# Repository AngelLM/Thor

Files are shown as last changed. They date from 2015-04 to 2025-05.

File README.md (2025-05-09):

<h1 align="center">
 <a href="http://thor.angel-lm.com">
    <picture>
      <source height="80" media="(prefers-color-scheme: dark)" srcset="doc/logo_dark.svg">
      Fiber
    </picture>
  </a>

 <br>

 <a href="http://thor.angel-lm.com/">
     
 </a>
 <a href="http://thor.angel-lm.com/worldwide/">
     
 </a>
 <a href="http://thor.angel-lm.com/forums/">
     
 </a>
 <a href="https://discord.com/invite/a5dSVqSUK5">
     
 </a>
 <a href="https://creativecommons.org/licenses/by-sa/4.0/legalcode">
     
 </a>
</h1>
<p align="center">
 <em><b>Thor</b> is an open source, 3D printed, 6 degrees of freedom robotic arm. Designed to be affordable and accessible, Thor is ideal for educational settings, makers, and robotics enthusiasts. With a height of 625mm it has the capacity to lift up to 750g. Its yaw-roll-roll-yaw-roll-yaw configuration is common in industrial manipulators.</em>
</p>
<p align="center">
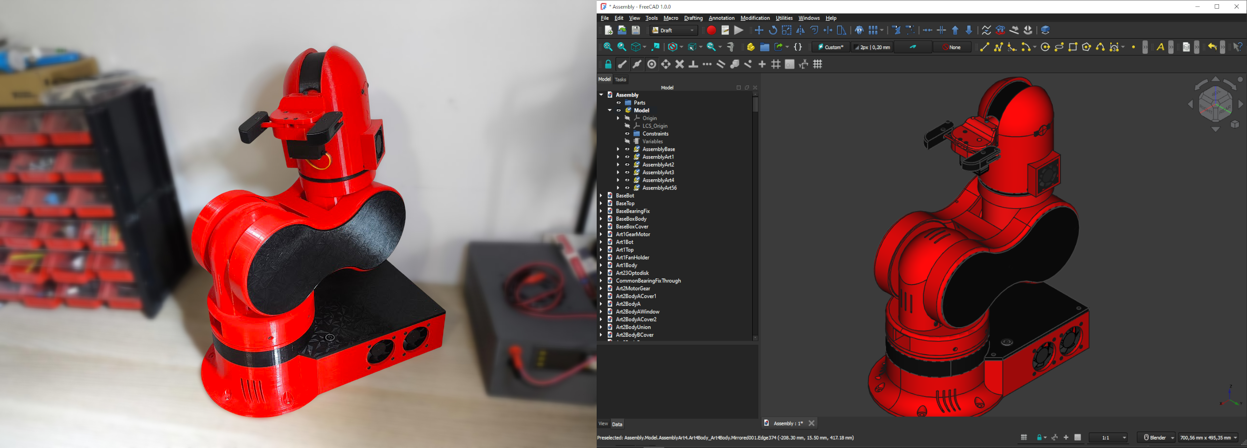
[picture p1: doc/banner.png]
 
</p>

## ✨ Key Features

- 🧩 **Born Open Source**: Designed using open source software such as FreeCAD, KiCAD, GRBL, RRF and ROS.
- 🕊️ **Released Open Source**: All source files published under CC-BY-SA-4.0 license.
- 💰 **Low Cost**: Hardware cost below 350€.
- 📚  **Suitable for education**: Perfect for robotics courses in schools and universities, there are already success cases!
- 🧰 **G-code Controlled**: Uses the same language as 3d printers and CNCs to move.
- 🐳 **ROS2 Integration**: Available implementation using Docker for flexibility.

## 📦 Repository Structure
- `freecad-src` – Source files of 3D models created with FreeCAD
- `mods` – Modified models and improvements to standard models
- `stl` – Printable STL files
- `step` – STEP files

## 🔗 Related Repositories
- [**Thor-ROS**](https://github.com/AngelLM/Thor-ROS): ROS2 & Moveit2 configuration files and packages to work with Thor.
- [**ThorControlPCB**](https://github.com/AngelLM/ThorControlPCB): Source & manufacture files of Arduino Mega shield designed to control Thor.
- [**Asgard**](https://github.com/AngelLM/Asgard): Control software for thor motors with a simple interface.

## 🚀 Getting Started

1. **Read the Documentation**: Comprehensive guides on printing, assembly, electronics, and firmware are available at [thor.angel-lm.com/documentation](http://thor.angel-lm.com/documentation/).
2. **Print the Parts**: Use the STL files in this repository.
3. **Get the Hardware**: Take a look to the [Bill of Materials](http://thor.angel-lm.com/documentation/bom/).
4. **Assemble the Robot**: See [here](http://thor.angel-lm.com/documentation/assembly/) for assembly videos and interactive instructions. 
5. **Assemble & Setup the Electronics**: The [Wiring & Setup](http://thor.angel-lm.com/documentation/electronics/) guide will help you prepare your electronic board and make the hardware connections. 
6. **Install the Firmware**: Depending on which electronics you have chosen, you will have to perform a different firmware configuration. [This page](http://thor.angel-lm.com/documentation/firmware/) explains the steps to follow.
7. **Control the Robot**: Use Asgard to move the robot. [Here](http://thor.angel-lm.com/documentation/control-software/) is how to do it.

## 🧠 Technical Specifications

- **Degrees of Freedom**: 6 (yaw-roll-roll-yaw-roll-yaw).
- **Height Stretched**: 625mm (without end effector).
- **Payload Capacity**: 750g max (including end effector weight).
- **Motors**: Stepper motors.
- **Electronics**: DIY PCB or commercial boards.
- **Transmission**: 3D printed gears, GT2 pulleys and belts.
- **Software**: FreeCAD, KiCAD, GRBL, RRF, ROS2.

## 📚 Additional Resources

- 🌐 **Official Website**: [thor.angel-lm.com](http://thor.angel-lm.com/)
- ❓ **Frequently Asked Questions**: [FAQ](http://thor.angel-lm.com/faq/)
- 💬 **Thor Community Forums**: [Thor Forums](http://thor.angel-lm.com/forums/)
- 💬 **Thor Discord Server**: [Thor Robot Community](https://discord.com/invite/a5dSVqSUK5)

## 🤝 Contributing

Contributions are welcome! If you'd like to improve Thor — whether it's design, documentation, or code — feel free to open an [Issue](https://github.com/AngelLM/Thor/issues) or submit a Pull Request.

## 📜 License

Thor is licensed under the [Creative Commons Attribution-ShareAlike 4.0 International License](https://creativecommons.org/licenses/by-sa/4.0/legalcode). You’re free to use, modify, and distribute this project under its terms.

## 🎥 Videos

Watch on YouTube (https://www.youtube.com/watch?v=F2CDeHrFr2k)

Watch on YouTube (https://www.youtube.com/watch?v=e0BGN1eIjiI)

Watch on YouTube (https://www.youtube.com/watch?v=nDCN46trJvs)

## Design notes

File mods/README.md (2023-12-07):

# Modifications

In this folder you'll find the FreeCAD, STEP and STL files for modifications that some users did. 

<br/>

## Easier printing

### These modifications make Thor easier to print (split parts or smaller modifications). 

<br/>

* [Danny-VdH](https://github.com/Danny-VdH) 
    * Art2BodyASmall, Art2BodyBSmall, Art2BodyBCoverSmall & Art4Body modifications

<br/>

* [Ctrl-Alt-Dude](http://www.thingiverse.com/ctrl-alt-dude/about)
    * BaseBot190mm modification (Deprecated)

<br/>

## End Effectors

### User-designed tools and end effectors for Thor

<br/>

* [ImerNChavez](https://github.com/imernchavez)
    * SuctionCupToolHolder

<br/>

## Tolerances and different hardware

### Modifications to parts that improve print tolerance or serve to use components other than those listed in the BOM.

<br/>

* [se1exin](https://github.com/se1exin) 
    * Art4BearingRing_5.98mm_Balls

<br/>

Thank you guys ;)

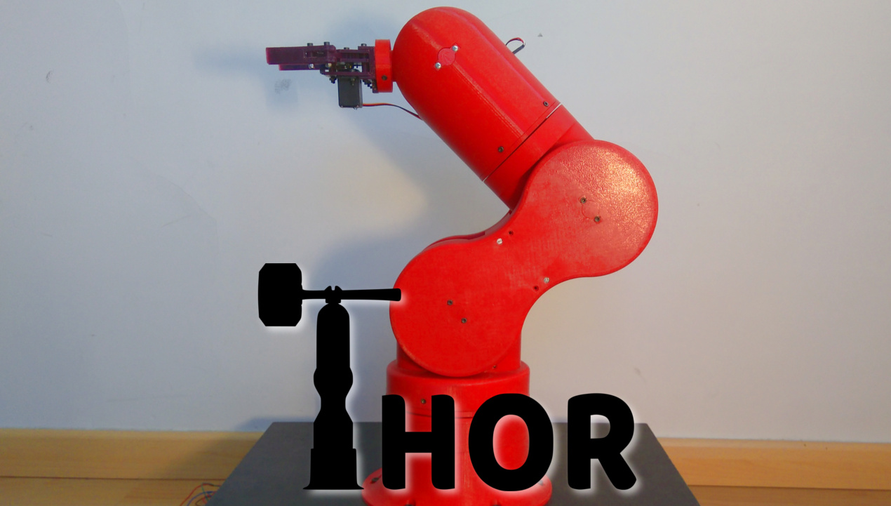
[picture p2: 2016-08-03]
doc/main.jpg

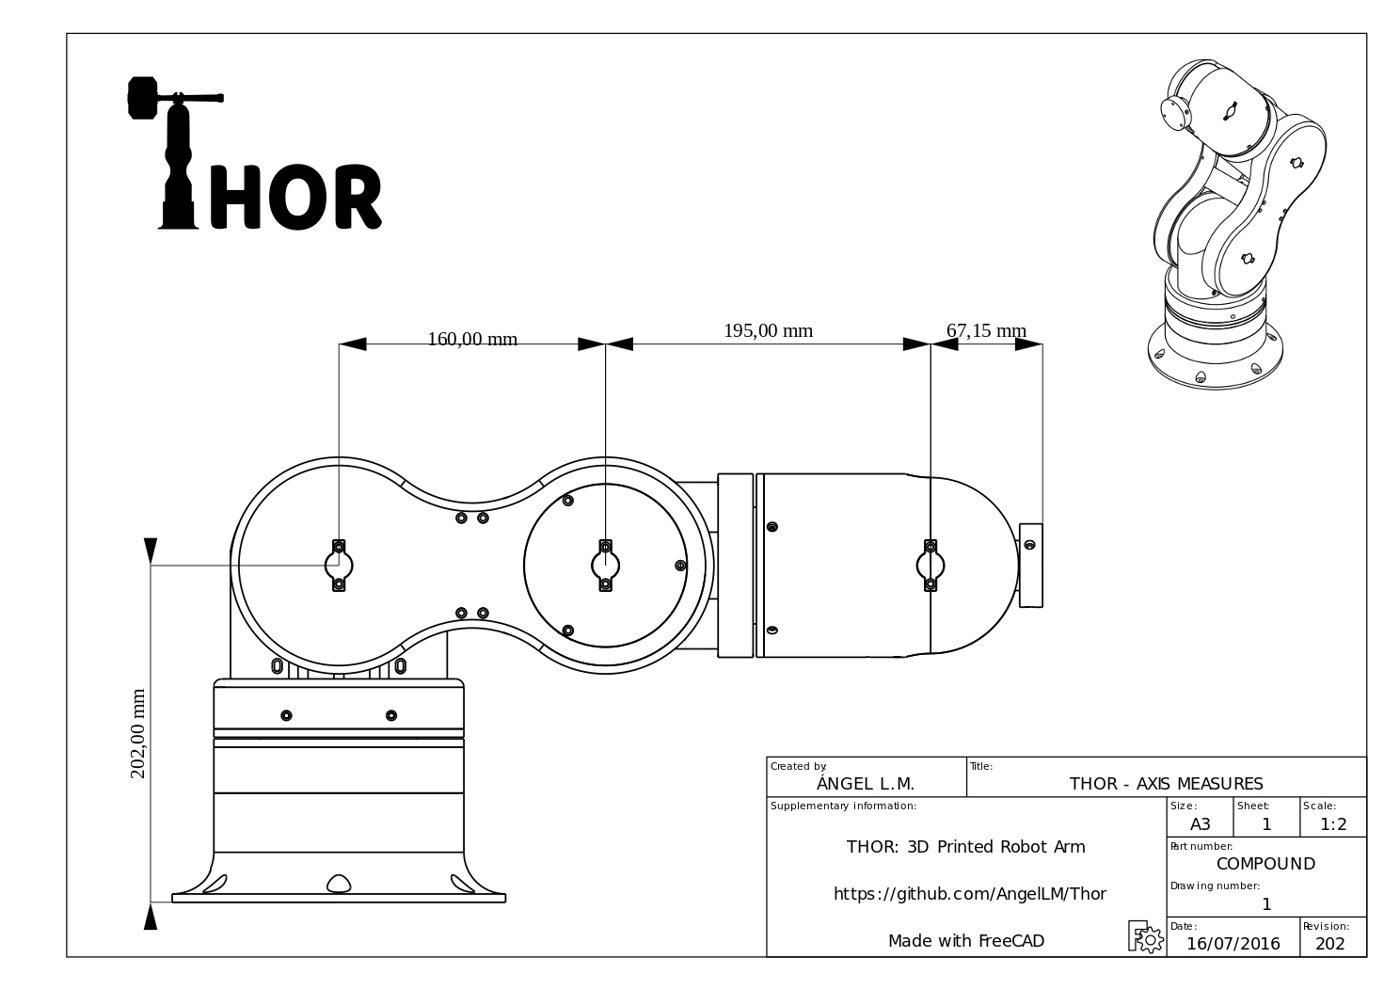
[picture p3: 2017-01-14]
doc/ThorDimensions.png

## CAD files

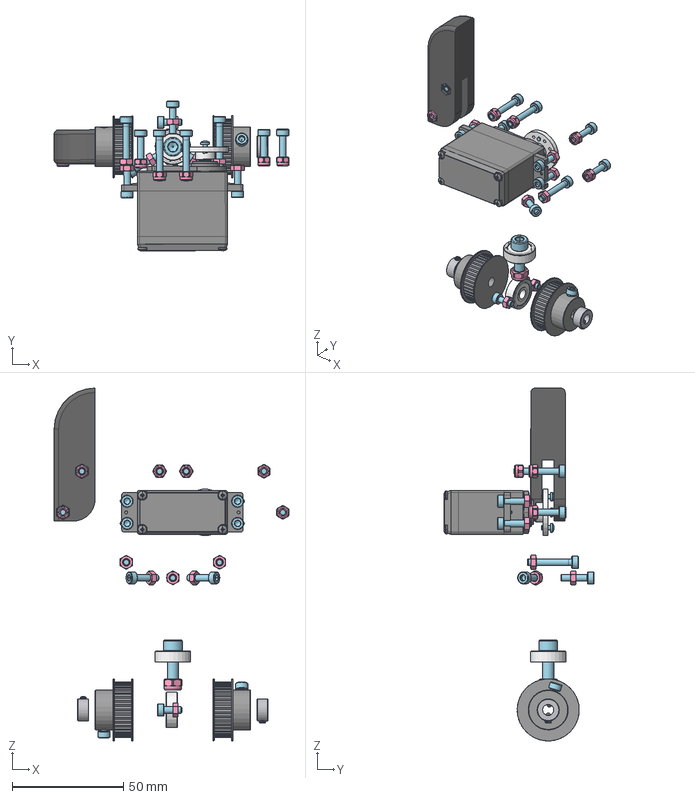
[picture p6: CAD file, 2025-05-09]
freecad-src/AssemblyArt56.FCStd
105.8 x 67.6 x 159.0 mm
Bearing 625ZZ x 2
Servomotor001
WheelHorn
Unnamed1_GripperFinger_mirrored
M3-Nut x 2
M3-Nut208 x 2
M3x12-Screw147 x 2
M3-Nut209 x 2
M3x12-Screw148 x 2
M3x12-Screw158 x 2
M3x20-Screw x 2
M2x6-Screw x 2
M3x12-Screw150 x 2
M3-Nut210 x 2
M3x20-Screw041 x 2
M3-Nut211 x 2
M3-Nut212 x 2
M3-Nut213 x 2
M3x20-Screw042 x 2
M3-Nut222 x 2
M3-Nut214 x 2
M3x20-Screw043 x 2
M3x12-Screw159 x 2
M3-Nut215 x 2
M3x12-Screw152 x 2
M3-Nut216 x 2
M3-Nut217 x 2
M3x12-Screw160 x 2
M3x12-Screw161 x 2
M3x12-Screw155 x 2
M3-Nut019 x 2
M3-Nut018 x 2
M3-Nut218 x 2
M3x8-Screw x 2
M3-Nut219 x 2
M3x6-Screw x 2
M5x16-Screw x 2
M3x8-Screw001 x 2
M3x6-Screw001 x 2
M5-Nut x 2
M3x12-Screw156 x 2
M2x4-Screw001 x 2
M3x12-Screw x 2
M3x12-Screw157 x 2
M3-Nut220 x 2
M3-Nut221 x 2
M2x4-Screw x 2
temp_import.STEP x 2
temp_import.step x 2

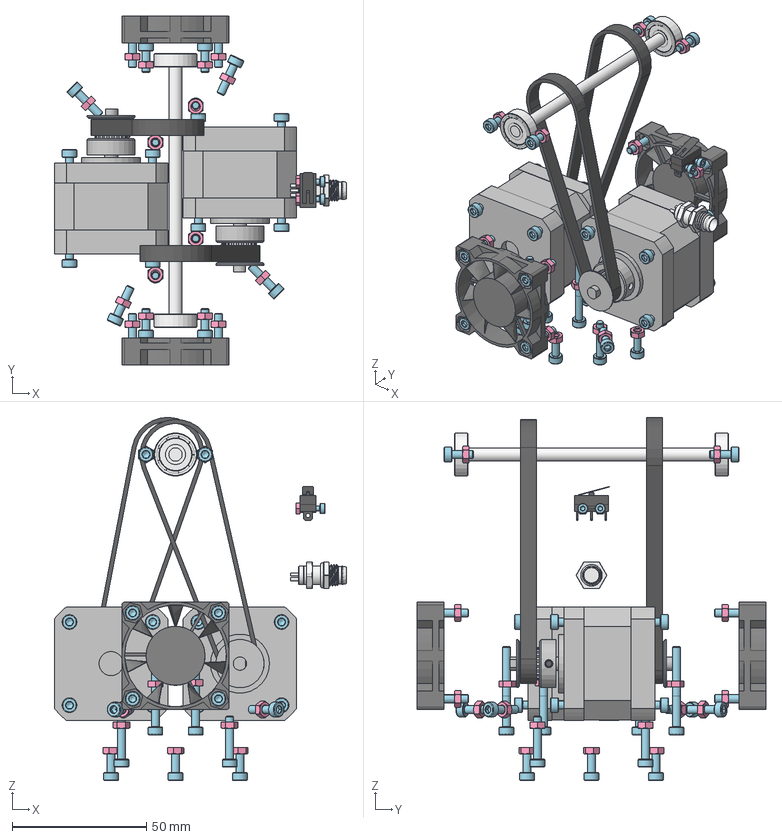
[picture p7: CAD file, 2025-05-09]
freecad-src/AssemblyArt4.FCStd
108.9 x 130.0 x 135.3 mm
NEMA-17_Stepper_Motor_34mm x 2
GT2x20Pulley x 2
M3GrubScrew x 2
Bearing 625ZZ x 2
fan-40x40mm x 2
GT2-208mm x 2
Micro-endstop
M3-Nut005 x 2
M3-Nut037 x 2
M3-Nut006 x 2
M2-Nut x 2
M3-Nut019 x 2
M3-Nut008 x 2
M3-Nut021 x 2
M3-Nut040 x 2
M3-Nut041 x 2
M3-Nut039 x 2
M3-Nut020 x 2
M3-Nut018 x 2
M3-Nut017 x 2
M3-Nut024 x 2
M3-Nut038 x 2
M3-Nut042 x 2
M3-Nut044 x 2
M3-Nut022 x 2
M3-Nut023 x 2
M3-Nut046 x 2
M3-Nut047 x 2
M3-Nut043 x 2
M3-Nut045 x 2
M3-Nut048 x 2
M3-Nut007 x 2
M3-Nut065 x 2
M3-Nut054 x 2
M3-Nut x 2
M3-Nut066 x 2
M3x16-Screw008 x 2
M2-Nut006 x 2
M3x16-Screw005 x 2
M3x16-Screw006 x 2
M3x16-Screw007 x 2
M3x8-Screw006 x 2
M3x8-Screw005 x 2
M3x8-Screw008 x 2
M3x25-Screw x 2
M3x30-Screw005 x 2
M3x30-Screw006 x 2
M3x8-Screw007 x 2
M3x30-Screw007 x 2
M3x12-Screw006 x 2
M3x30-Screw008 x 2
M3x12-Screw008 x 2
M3x12-Screw005 x 2
M2x6-Screw x 2
M2x6-Screw001 x 2
M3x12-Screw007 x 2
M3x25-Screw017 x 2
M3x25-Screw018 x 2
M3x25-Screw019 x 2
M3x25-Screw020 x 2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

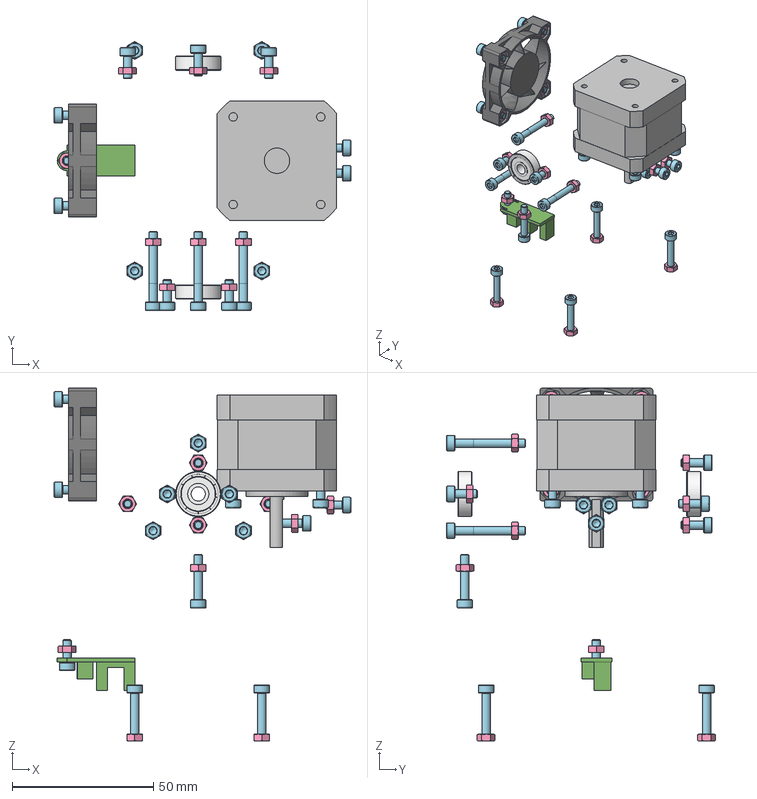
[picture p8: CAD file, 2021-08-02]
freecad-src/AssemblyArt3.FCStd
105.0 x 95.2 x 124.9 mm
NEMA-17_Stepper_Motor_34mm
fan-40x40mm
Bearing 625ZZ x 2
M3-Nut037 x 2
M3-Nut048 x 2
M3-Nut049 x 2
M3-Nut031 x 2
M3-Nut033 x 2
M3-Nut038 x 2
M3-Nut024 x 2
M3-Nut027 x 2
M3-Nut022 x 2
M3-Nut032 x 2
M3-Nut025 x 2
M3-Nut028 x 2
M3-Nut029 x 2
M3-Nut030 x 2
M3-Nut x 2
M3-Nut050 x 2
M3-Nut035 x 2
M3-Nut036 x 2
M3-Nut026 x 2
M3-Nut023 x 2
M3-Nut051 x 2
M3-Nut052 x 2
M3x8-Screw006 x 2
M3x8-Screw007 x 2
M3x25-Screw x 2
M3x8-Screw011 x 2
M3x8-Screw008 x 2
M3x8-Screw005 x 2
M3x8-Screw012 x 2
M3x8-Screw x 2
M3x25-Screw003 x 2
M3x25-Screw004 x 2
M3x12-Screw005 x 2
M3x12-Screw004 x 2
M3x6-Screw001 x 2
M3x16-Screw x 2
M3x12-Screw x 2
M3x6-Screw x 2
M3x12-Screw006 x 2
M3x8-Screw019 x 2
M3x8-Screw018 x 2
M3x8-Screw017 x 2
M3x16-Screw006 x 2
M3x8-Screw020 x 2
M3x16-Screw005 x 2
M3x8-Screw021 x 2
M3x16-Screw007 x 2
M3x16-Screw008 x 2

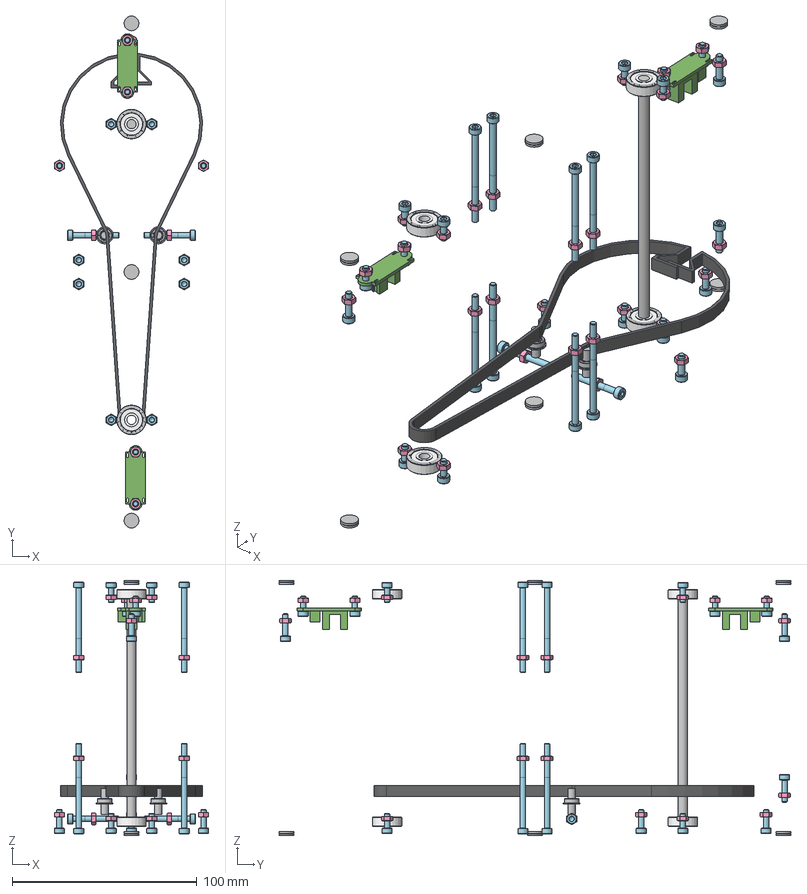
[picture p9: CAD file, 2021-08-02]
freecad-src/AssemblyArt2.FCStd
83.4 x 277.0 x 138.2 mm
Bearing 625ZZ x 4
OptoSwitch002 x 2
MF84ZZ x 2
GT2Belt001
M3-Nut073 x 2
M3x8-Screw035 x 2
M3x25-Screw001 x 2
M3x8-Screw x 2
M3x8-Screw034 x 2
M3-Nut075 x 2
M3-Nut x 2
M3x8-Screw036 x 2
M3-Nut074 x 2
M3x8-Screw037 x 2
M3x10-Screw010 x 2
M3x10-Screw011 x 2
M3-Nut076 x 2
M3x10-Screw x 2
M3x25-Screw x 2
M3-Nut072 x 2
M3-Nut070 x 2
M3-Nut071 x 2
M3-Nut077 x 2
M3-Nut079 x 2
M3-Nut078 x 2
M3x8-Screw041 x 2
M3x46-Screw019 x 2
M3-Nut086 x 2
M3x8-Screw039 x 2
M3-Nut092 x 2
M3-Nut094 x 2
M3x46-Screw020 x 2
M3x46-Screw025 x 2
M3-Nut085 x 2
M3-Nut081 x 2
M3-Nut083 x 2
M3-Nut087 x 2
M3x8-Screw038 x 2
M3x8-Screw040 x 2
M3x12-Screw x 2
M3x46-Screw021 x 2
M3x12-Screw003 x 2
M3x46-Screw022 x 2
M3x46-Screw023 x 2
M3x46-Screw024 x 2
M3-Nut082 x 2
M3-Nut080 x 2
M3x46-Screw x 2
M3-Nut084 x 2
M3-Nut088 x 2
M3-Nut090 x 2
M3-Nut089 x 2
M3-Nut091 x 2
M3-Nut093 x 2
M3-Nut095 x 2
M3-Nut096 x 2
M3x8-Screw057 x 2
M3x8-Screw058 x 2
M3x8-Screw059 x 2
M3x12-Screw004 x 2

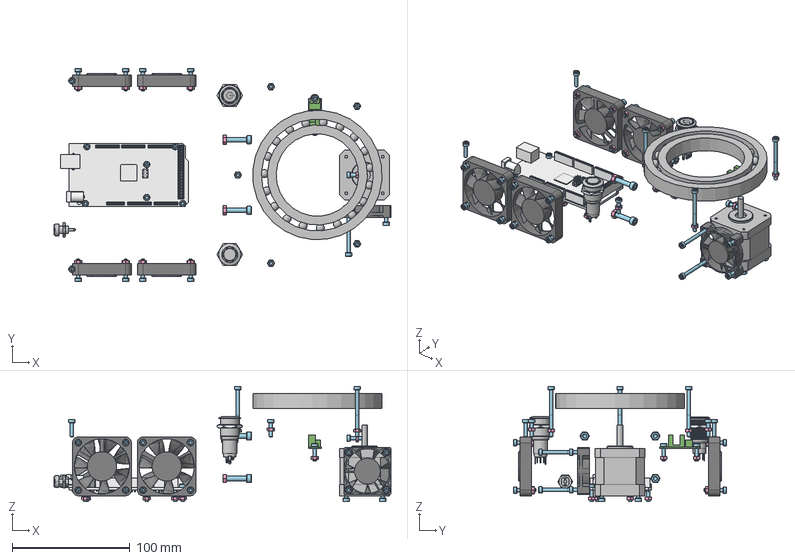
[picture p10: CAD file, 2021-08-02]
freecad-src/AssemblyBase.FCStd
286.1 x 181.0 x 98.0 mm
Nema-17-motor-40mm-final
OptoSwitch002
fan-40x40mm
16mmOnOffButton
16mmPushButton
fan-50x50mm x 4
Arduino-mega
DJ Jack 2,1mm panel mount
16mmNut x 2
Bearing 16014zz
M3x16-Screw114 x 2
M3x40-Screw x 2
M3-Nut172 x 2
M3x12-Screw061 x 2
M3-Nut173 x 2
M3-Nut174 x 2
M3x16-Screw115 x 2
M3x12-Screw062 x 2
M4x20-Screw004 x 2
M3-Nut122 x 2
M3-Nut175 x 2
M3-Nut124 x 2
M3x40-Screw012 x 2
M3x16-Screw116 x 2
M3x12-Screw045 x 2
M3-Nut176 x 2
M3-Nut x 2
M3-Nut177 x 2
M3x10-Screw x 2
M3-Nut178 x 2
M3-Nut179 x 2
M3-Nut180 x 2
M3-Nut181 x 2
M3x14-Screw001 x 2
M3-Nut182 x 2
M3x16-Screw x 2
M3-Nut183 x 2
M3x16-Screw117 x 2
M3x16-Screw118 x 2
M3x12-Screw063 x 2
M3-Nut184 x 2
M4x20-Screw005 x 2
M3x12-Screw064 x 2
M3x16-Screw119 x 2
M3x16-Screw120 x 2
M3-Nut185 x 2
M3-Nut186 x 2
M3-Nut187 x 2
M3-Nut137 x 2
M3x16-Screw121 x 2
M3-Nut138 x 2
M3-Nut188 x 2
M3-Nut189 x 2
M3-Nut190 x 2
M3x16-Screw122 x 2
M3x40-Screw013 x 2
M3x30-Screw x 2
M3x30-Screw009 x 2
M3x30-Screw010 x 2
M3-Nut142 x 2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

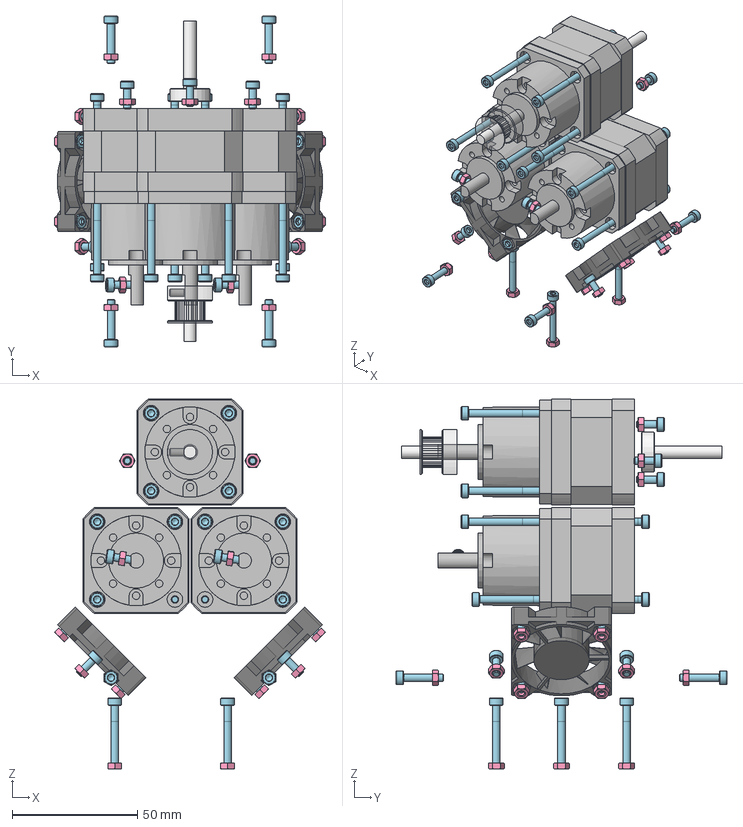
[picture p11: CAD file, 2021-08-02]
freecad-src/AssemblyArt1.FCStd
108.1 x 132.0 x 147.6 mm
Bearing 625ZZ
Nema17GearBox x 3
fan-40x40mm x 2
GT2x20PulleyModified
M3GrubScrew
M3x8-Screw070 x 2
M3-Nut x 2
M3x25-Screw x 2
M3x25-Screw005 x 2
M3-Nut052 x 2
M3x25-Screw006 x 2
M3-Nut053 x 2
M3-Nut054 x 2
M3-Nut055 x 2
M3-Nut056 x 2
M3-Nut057 x 2
M3-Nut058 x 2
M3-Nut059 x 2
M3-Nut060 x 2
M3-Nut061 x 2
M3x8-Screw071 x 2
M3-Nut062 x 2
M3x8-Screw x 2
M3x8-Screw055 x 2
M3x40-Screw x 2
M3x40-Screw062 x 2
M3x8-Screw056 x 2
M3x20-Screw022 x 2
M3x8-Screw072 x 2
M3x8-Screw073 x 2
M3x8-Screw074 x 2
M3-Nut063 x 2
M3-Nut064 x 2
M3-Nut065 x 2
M3-Nut066 x 2
M3-Nut067 x 2
M3x8-Screw075 x 2
M3-Nut068 x 2
M3x8-Screw061 x 2
M3x8-Screw062 x 2
M3-Nut069 x 2
M3-Nut070 x 2
M3x40-Screw063 x 2
M3x40-Screw064 x 2
M3x20-Screw023 x 2
M3x40-Screw065 x 2
M3x40-Screw066 x 2
M3x40-Screw067 x 2
M3x40-Screw068 x 2
M3x20-Screw024 x 2
M3x20-Screw025 x 2
M3x20-Screw026 x 2
M3x40-Screw071 x 2
M3x20-Screw027 x 2
M3x40-Screw072 x 2
M3x20-Screw028 x 2
M3x20-Screw x 2
M3x8-Screw063 x 2
M3x8-Screw064 x 2
M3x16-Screw007 x 2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

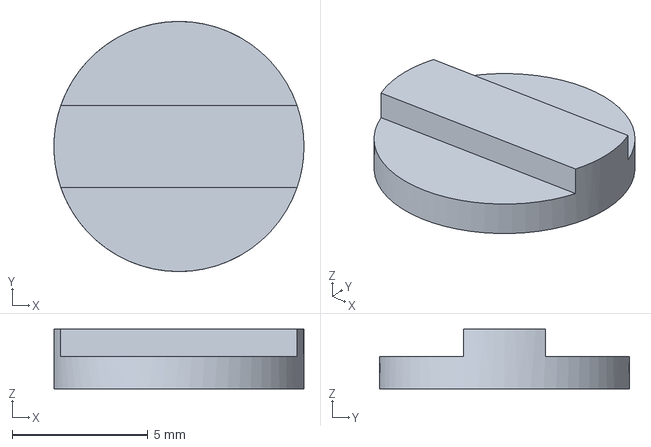
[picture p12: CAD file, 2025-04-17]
mods/freecad-src/Art1Top_1_Stopper.FCStd
9.19 x 9.20 x 2.20 mm

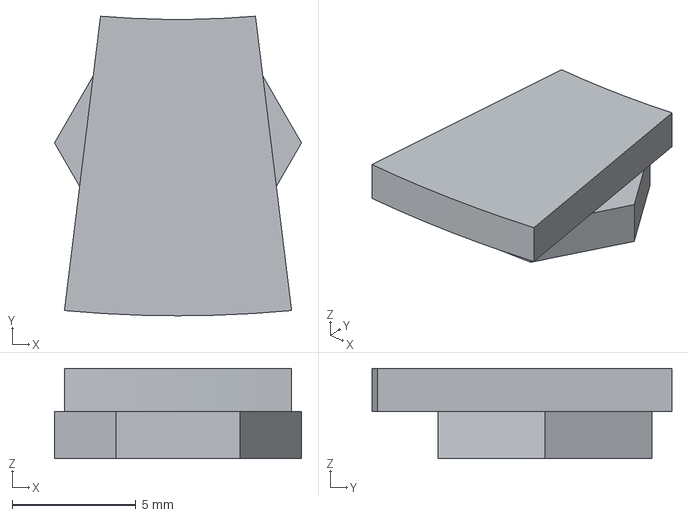
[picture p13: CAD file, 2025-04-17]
mods/step/Art4BearingRing_Stopper.step
10.0 x 12.1 x 3.65 mm

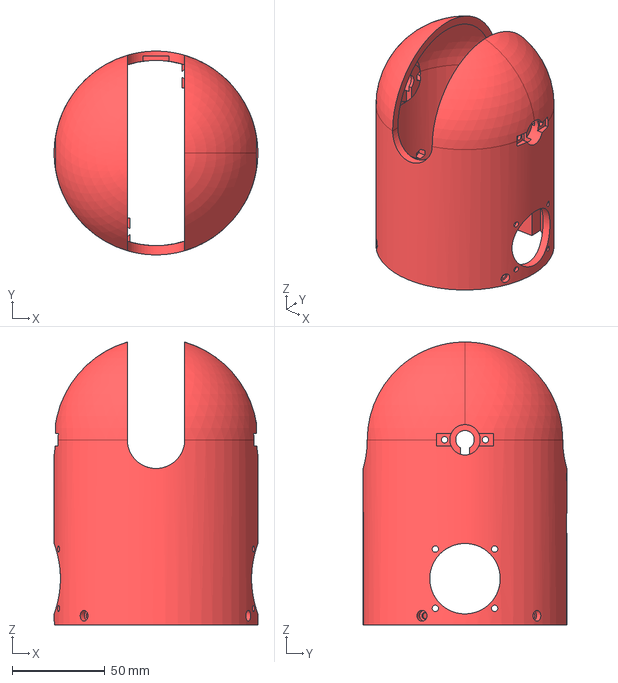
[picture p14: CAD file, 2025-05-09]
step/Art4Body.step
110.0 x 110.0 x 152.8 mm

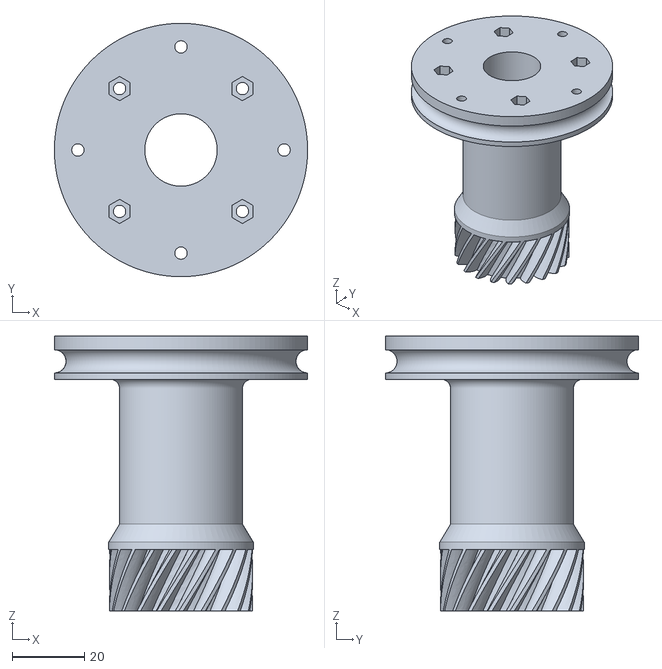
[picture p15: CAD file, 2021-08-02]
stl/Art4TransmissionColumn.stl
70.0 x 70.0 x 76.0

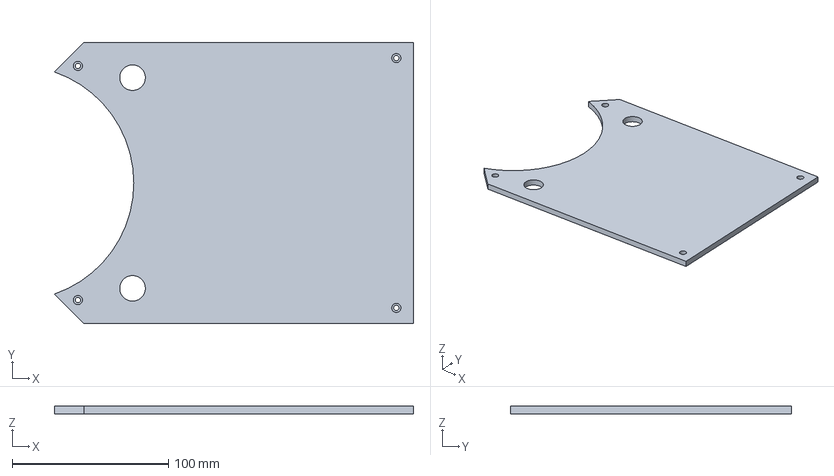
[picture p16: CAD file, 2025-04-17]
mods/freecad-src/BaseBoxCover-FlySuper8Pro.FCStd
230.0 x 180.0 x 5.00 mm

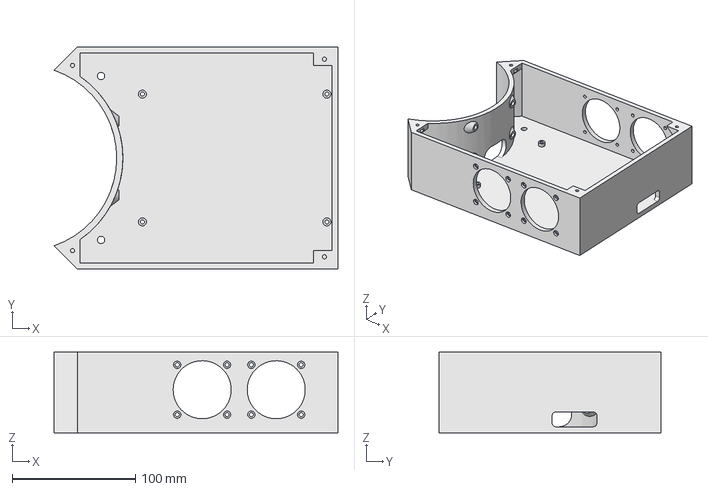
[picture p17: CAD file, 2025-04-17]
mods/step/BaseBoxBody-FlySuper8Pro.step
230.0 x 180.0 x 65.5 mm

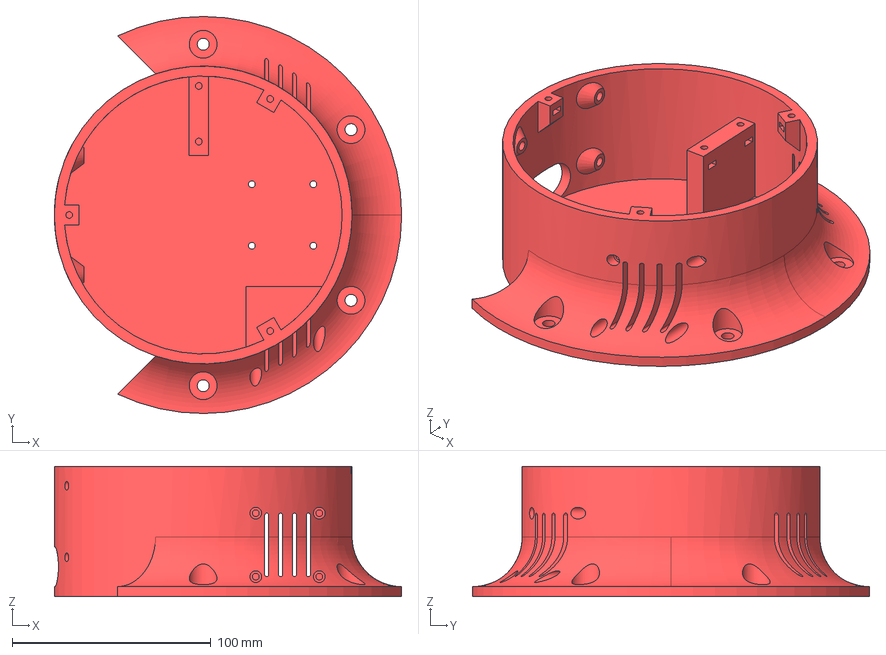
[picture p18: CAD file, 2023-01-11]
step/BaseBot.step
175.0 x 200.0 x 65.5 mm

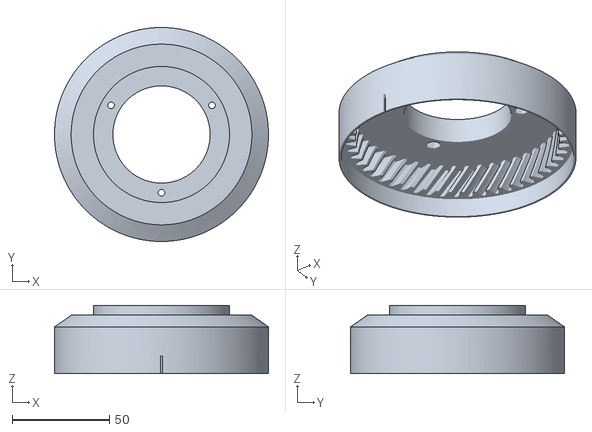
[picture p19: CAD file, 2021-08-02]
stl/Art1Bot.stl
110.1 x 110.1 x 35.0

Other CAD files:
freecad-src/Assembly.FCStd
freecad-src/Art4Body.fcstd
mods/freecad-src/Art1Top_Splitted_A.FCStd
mods/step/BaseBoxCover-FlySuper8Pro.step
freecad-src/Art1Body.fcstd
freecad-src/Art1FanHolder.FCStd
freecad-src/Art1GearMotor.fcstd
freecad-src/Art1OptoFix.fcstd
freecad-src/Art1Top.fcstd
freecad-src/Art23Optodisk.fcstd
freecad-src/Art2BodyACover1.fcstd
freecad-src/Art2BodyACover2.fcstd
freecad-src/Art2BodyAWindow.fcstd
freecad-src/Art2BodyB.fcstd
freecad-src/Art2BodyBCover.fcstd
freecad-src/Art2BodyUnion.FCStd
freecad-src/Art2MotorGear.fcstd
freecad-src/Art2SideCover.FCStd
freecad-src/Art3Body.fcstd
freecad-src/Art3Body2.FCStd
freecad-src/Art3Pulley.fcstd
freecad-src/Art3TensionerBody.fcstd
freecad-src/Art3TensionerPulley.fcstd
freecad-src/Art4BearingFix.fcstd
freecad-src/Art4BearingPlug.fcstd
freecad-src/Art4BearingRing.fcstd
freecad-src/Art4BodyBot.fcstd
freecad-src/Art4BodyFan.fcstd
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

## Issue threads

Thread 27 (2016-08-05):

Smoothie

arthurwolf, 2016-08-05:
Cool project !

How about using a Smoothieboard and the Smoothie firmware instead of a grbl-based solution ?
We make it very simple to add new "arm solutions" to convert cartesian coordinates into actuator coordinates ( https://github.com/Smoothieware/Smoothieware/tree/edge/src/modules/robot/arm_solutions )
Also, it's 32bits, so it'll be faster and smoother. And it's got a larger community, is very actively developed, etc ...
We'd send you a free board if you say you'll add the code to smoothie.

Cheers :)

AngelLM, 2016-08-05:
Arthurwolf, it would be awesome!
Of course I'll share everything I'll do with the Smothieboard :)

I have seen that the Smothieboard can control up to 5 steppers, isn't it? As Thor has 6 DOF (without counting the gripper) I think I will need add something to control the last one.

Regards!

arthurwolf, 2016-08-06:
Hey.

Yes, you'll need to add an external driver to it. It's very easy to do, you can use any pin for this.
Can you email me at wolf.arthur@gmail.com with your full shipping address and phone number ?

Thanks :)
Cheers.

AngelLM, 2016-08-18:
Package received!
Thank you very much =)
Let's keep in touch!

Closed 2016-08-18.

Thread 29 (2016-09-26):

Malfunction due to steppers overheat

AngelLM, 2016-09-26:
Steppers overheat causing printed gears deformation and malfunction of the arm.
**Possible causes:**
1. Wrong stepper drivers or wrong configuration.
2. Not enough refrigeration. Actual design does not allow air flow.
**Possible solutions:**
1. Find other driver that works better.
2. Modify the actual design to allow steppers refrigeration.
3. Use a more heat-resistant material to print the gears: ABS, Nylon, HIPS, PET...

AngelLM, 2016-09-26:
I'll try to solve this keeping the A4988 drivers, modifying the design and trying to print the gears with other materials.

Danny-VdH, 2016-09-27:
I gone use Microstep Driver ST-7128 from stepperonline
My gears are printed with ABSPlus from Stratasys. (If you need some let me know)
When I finished the robot I will give feedback
I going to look to buildin a ventilation systeem into the second articulation to prevent the heating.

AngelLM, 2016-09-29:
I'll be waiting for that awesome feedback!

I just pushed a new modification of the design, allowing the air-flow and the installation of 40mm fans. Before merging it to the main branch I have to test it.

Danny-VdH, 2016-10-02:
Can't wait to see your solution!

AngelLM, 2016-11-07:
Solved on dd6c5e3!
Yay, the new design enable the air flow and refrigeration of the steppers. Now they don't melt the structure or gears, making possible the arm activity for a long period of time.

Closing this!

Closed 2016-11-07.

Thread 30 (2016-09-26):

Inverse Kinematics implementation

AngelLM, 2016-09-26:
It could be nice to have the IK implemented, in order to control the robot using XYZ coordinates and a rotation matrix.

AngelLM, 2016-09-26:
Currently working on it.

Danny-VdH, 2016-09-27:
The best open source so far (c# ), used in my software and working well.
Made some little modification to it.

`    //---------------------------------------------------------------------------
    float[] _InverseK(float Xreal, float Yreal, float Zreal, float alfa1, float beta1, float gamma1)
    {
        float PI = 3.141592654f;
        float Rad = PI / 180;
        float Grad = 180 / PI;

        //initial values   of point P wrist, Px,Py,Pz

        //orientation matrix parameters
        float cosalfa1 = Mathf.Cos(alfa1 * Rad);
        float senalfa1 = Mathf.Sin(alfa1 * Rad);
        float cosbeta1 = Mathf.Cos(beta1 * Rad);
        float senbeta1 = Mathf.Sin(beta1 * Rad);
        float cosgamma1 = Mathf.Cos(gamma1 * Rad);
        float sengamma1 = Mathf.Sin(gamma1 * Rad);

        //X-Y-Z SET ANGLES
        //X'
        float r11 = (cosalfa1 * cosbeta1);
        float r21 = (senalfa1 * cosbeta1);
        float r31 = -senbeta1;       
        //Y'
        float r12 = (cosalfa1 * senbeta1 * sengamma1) - (senalfa1 * cosgamma1);
        float r22 = (senalfa1 * senbeta1 * sengamma1) + (cosalfa1 * cosgamma1);
        float r32 = (cosbeta1 * sengamma1);                             
        //Z'
        float r13 = (cosalfa1 * senbeta1 * cosgamma1) + (senalfa1 * sengamma1);
        float r23 = (senalfa1 * senbeta1 * cosgamma1) - (cosalfa1 * sengamma1);
        float r33 = (cosbeta1 * cosgamma1);

        float a2 = LongBrazo;
        float d4 = LongAntBr + LongMunec / 2;
        float d6 = LongMunec / 2 + LongTool / 2;
//        float d4 = LongAntBr;
//        float d6 = LongMunec + LongTool;
        float a22 = a2 * a2;
        float d42 = d4 * d4;
        //int d = 0;

        float xc = Xreal - d6 * r13;
        float yc = Yreal - d6 * r23;
        float zc = (Zreal - AlturaH) - d6 * r33;

        float x2 = xc * xc;
        float y2 = yc * yc;
        float z2 = zc * zc;
        //float d22 = d * d;

        //Calculate theta1
        theta1 = (Mathf.Atan2(yc, xc)) * Grad;

        //Calculate theta3
        float K = (x2 + y2 + z2 - a22 - d42) / (2 * a2);
        float Raiz3 = Mathf.Sqrt(Mathf.Abs(Mathf.Abs(d42) - (K * K)));
//        float Raiz3 = Mathf.Sqrt(Mathf.Abs(d42) - (K * K));
        theta3 = -(Mathf.Atan2(K, Raiz3)) * Grad;

        float costheta1 = Mathf.Cos(theta1 * Rad);
        float sentheta1 = Mathf.Sin(theta1 * Rad);
        float costheta3 = Mathf.Cos(theta3 * Rad);
        float sentheta3 = Mathf.Sin(theta3 * Rad);

        float Y = (-a2 * costheta3) * zc - (costheta1 * xc + sentheta1 * yc) * (d4 - a2 * sentheta3);
        float X = ((a2 * sentheta3 - d4) * zc + (a2 * costheta3) * (costheta1 * xc + sentheta1 * yc));

        //Calculate theta2
        float theta23 = (Mathf.Atan2(Y, X)) * Grad;
        theta2 = theta23 - theta3;
        float costheta2 = Mathf.Cos(theta2 * Rad);
        float sentheta2 = Mathf.Sin(theta2 * Rad);

        float costheta23 = (costheta2 * costheta3) - (sentheta2 * sentheta3);
        float sentheta23 = (sentheta2 * costheta3) + (costheta2 * sentheta3);

        //Calculate theta4
        Y = ((costheta1 * r23) - (sentheta1 * r13));
        X = (-(costheta1 * costheta23 * r13) - (sentheta1 * costheta23 * r23) + (sentheta23 * r33));

        theta4 = (Mathf.Atan2(Y, X)) * Grad;
        float costheta4 = Mathf.Cos(theta4 * Rad);
        float sentheta4 = Mathf.Sin(theta4 * Rad);

        //Calculate theta5
        Y = (-r13 * ((costheta1 * costheta23 * costheta4) + (sentheta1 * sentheta4)) - r23 * ((sentheta1 * costheta23 * costheta4) - (costheta1 * sentheta4)) + r33 * (sentheta23 * costheta4));
        X = (-r13 * (costheta1 * sentheta23) - r23 * (sentheta1 * sentheta23) - r33 * (costheta23));

        theta5 = (Mathf.Atan2(Y, X)) * Grad;
        float costheta5 = Mathf.Cos(theta5 * Rad);
        float sentheta5 = Mathf.Sin(theta5 * Rad);

        //Calculate theta6
        float Y2 = (-r11 * ((costheta1 * costheta23 * sentheta4) - (sentheta1 * costheta4)) - r21 * ((sentheta1 * costheta23 * sentheta4) + (costheta1 * costheta4)) + r31 * (sentheta23 * sentheta4));
        float X61 = (costheta1 * costheta23 * costheta4 + sentheta1 * sentheta4) * costheta5 - (costheta1 * sentheta23 * sentheta5);
        float X62 = (sentheta1 * costheta23 * costheta4 - costheta1 * sentheta4) * costheta5 - (sentheta1 * sentheta23 * sentheta5);
        float X63 = sentheta23 * costheta4 * costheta5 + costheta23 * sentheta5;
        float X2 = r11 * X61 + r21 * X62 - r31 * X63;

        theta6 = (Mathf.Atan2(Y2, X2)) * Grad;
        float costheta6 = Mathf.Cos(theta6 * Rad);
        float sentheta6 = Mathf.Sin(theta6 * Rad);

        // return all calculated angles
        return new float[] { theta1, theta2, theta3, theta4, theta5, theta6 };
    }
    //---------------------------------------------------------------------------
`
Hope it helps.

Danny-VdH, 2016-09-27:
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

Danny-VdH, 2016-09-27:
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

AngelLM, 2016-09-29:
Wow it looks nice, thank you! I'll take a look.
I was stuck on the Rotation Matrix and how to send a Gcode with those 9 parameters. I'm working on it :)

b-adkins, 2016-12-10:
Why not use [Robot Operating System](http://www.ros.org/)? URDF and TF handle inverse kinematics pretty painlessly. [MoveIt](http://moveit.ros.org/) makes planning pretty easy. It's already used by a [lot of robots](http://moveit.ros.org/robots/).

AngelLM, 2016-12-19:
Hi!
I never worked with ROS so... that's why I didn't use it. Maybe it could be a nice way to implement control... I'll look at it when I have time.
Thanks!

zisi, 2017-01-16:
Hey, you can also use kdl, http://www.orocos.org/kdl. It doesn't give analytical equations but it uses numerical methods to calculate the IK.

b-adkins, 2017-01-18:
FYI, KDL is MoveIt's default IK solver. ROS and MoveIt make it really easy to control the robot in either XYZ space or joint space.

b-adkins, 2017-01-23:
I set up Thor in ROS MoveIt!

I'm still getting my hands on all the parts, but in the meantime I did some coding... [Check it out!](https://github.com/b-adkins/thor_arm_moveit)

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

VictorLamoine, 2017-02-19:
:+1: for Robot Operating System.

You'll never reach alone the complexity of what you can find in ROS, plus there is no point in coding that again apart for fun or educational purposes.

Moving this robot towards ROS will allow very complex path planning with occupancy grids and collision avoidance; torque control, adding vision (2D/3D) sensors... well pretty much anything you can imagine on a modern industrial robot.

Cheers for this project :beer: It's awesome

AngelLM, 2017-04-16:
Hi all! I attempted to use KDL libraries when I was controlling the robot with 2 RAMPS boards. I had no enough time to make it work, so I moved to FK instead of IK.
@b-adkins That looks amazing! I'll take a look :)

AngelLM, 2021-08-09:
This task will be done in the Asgard repo, so I have taken note of it and closing this here.
Thanks for your help!

Closed 2021-08-09.

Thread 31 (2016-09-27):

Tool pins connector slip off.

AngelLM, 2016-09-27:
Pins, actually located on Art4Body piece, are glued to the printed piece. Due to use, glue stopped holding the pins and now it's impossible to connect the tool wires.
Possible solution: Design a small PCB that integrates the tool pins and the endstop as they are in the same side of the piece.

Danny-VdH, 2016-09-27:
I am going to forsee two tubes going through inside the robot, one for the electrical connection on a pcb board with connector and one for use of a suction vacuum system. Both will be connected with flexible tubes to the tool of the robot.

AngelLM, 2016-11-17:
I fixed it with two-part epoxy glue and it works very well... Closing this for now.

Closed 2016-11-17.

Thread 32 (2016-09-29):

Feedback sensors

AngelLM, 2016-09-29:
Currently the control of the arm is based on a open kinetic chain. The Zero (Home) position is set at the start and the subsequent movements are based on that reference.
The inclusion of encoders or potentiometers as angle sensors could allow a closed kinetic chain control and new features like recording movements manually.

Danny-VdH, 2016-10-02:
What do you thing about this solution?
http://wiki.seeedstudio.com/wiki/Grove_-_Rotary_Angle_Sensor

Danny-VdH, 2016-10-02:
I'm thinking to build a arduino uno inside the robot base to connect all the potmeters led neopixel ring, buttons and gripper servo motor, then connecting with serial com. to the outside connector to connect to the main (arduino mega board) circuit. It solves a lot of wires (could also be for other electronics to connect with , like fans for controlling the heating inside the robot) And it's a cheap solution!

Danny-VdH, 2016-10-02:
I'm gone make my own connector pcb board that connects over the arduino uno and the pcd boards with the potmeters on it in place of the homing sensors pcb's.

Danny-VdH, 2016-10-02:
You can use a soft serial communication between two arduino's, tested it already and work flawless!

Danny-VdH, 2016-10-03:
http://www.contelec.ch/nc/en/products.html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

Hollow shaft potmeter could be a good solution.

Blueicaro, 2016-10-20:
Hi, the industrial robots, from ABB (http://new.abb.com/products/robotics/es), use one resolver for each motor unit. Resolver gives two analogic signal. One signal is called X, and de other is called Y, with this signal you can have polar coordinates of the axis motor, so you have the angle of the axis motor.
Inside of the robot there is a boad called Serial Measure Board (SMB), this board have connected all resolver unit , read the resolvers and send information to the computer.
Resolver unit, are used to read position, and speed
 This is quite complex and expensive, but I think with the potmeter, as say Danny-VDH you can read the angle of the axis motor.
Using a board (arduino for example) inside the robot, reading the potometer, and sending the information to the main controler can be a good option.
Sending information in serial mode needs some protocol to avoid, and detect transmision errors, but this is easy to build it.
/BlueIcaro
P.D. I'm spanish, and my english is a little rusty, if you want we can discuss it in spanish.

CatalanCaptain, 2016-11-18:
What about hall effect sensor? You can place 3 in a 120º polar array board, and magnets on the other side.
The accuracy is as high as your ADC resolution can be.
I'm spanish too...

ppedro74, 2016-12-12:
@Danny-VdH

Can you post a supplier to the Wal200 potentiometer ?
I can't find the price neither were to buy.

Anyone knows the cost ?

i-make-robots, 2016-12-27:
I am using the as5045, same as in MANTIS. ~4K positions double Hall effect. Currently working on making the sensor into a single unit that can be independently tested and then dropped into an arm design where needed.

i-make-robots, 2016-12-27:
I hve seen an arm that uses LEDs, photoresistors, and slots cut in a disc. Measure the light level to find the angle. They claim millions of points per rotation, but do all their math on an fpga.

ppedro74, 2016-12-27:
Can you recommend a board/kit with the as5045 and the magnet ?

On Tue, Dec 27, 2016 at 11:58 AM, Dan Royer <notifications@github.com>
wrote:

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

i-make-robots, 2016-12-28:
i got one from http://madscientisthut.com/ and tweaked the firmware.  here's what I got: https://www.instagram.com/p/BOim_CBjiaU

ppedro74, 2016-12-28:
Dan,

Thanks for the tip !

i found more development pcb kits (digikey, mouser, farnell)

nice job.

I have the chip glue, tape = mess ...

1) Can you share the 3d print parts and the ball bearings you used ?

2) Are you using that solution with the robot arm ?

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

i-make-robots, 2016-12-28:
I'm not ready to share teh parts yet, tho I have in the past.  https://hackaday.io/project/945-5-axis-robot-arm  I'm currently trying to update my own arm design based on some good ideas in THOR.

ppedro74, 2016-12-29:
Dan,

Thanks for the feedback.

so far i'm researching potentiometer feedback alternatives. I'm following
you on Twitter, i'll keep an eye to see how your idea evolves.

Maybe i'll try to reproduce something similar my main issue is the board
size, and the space needed to fit in.

One question where you source the ball bearing ?

On Wed, Dec 28, 2016 at 12:01 PM, Dan Royer <notifications@github.com>
wrote:

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

i-make-robots, 2016-12-29:
FWIW I post more to instagram.  I use a local company that supplies
bearings to industry.  They have a big warehouse an hour away and are nice
enough to tell me which bearings are rare so I don't use some wonky "only 2
available in the world" size.

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

--
Dan Royer, Owner, Marginally Clever Robots
<https://www.marginallyclever.com/>
Ph: +1 (604) 259-9564
Mo: +1 (604) 916-2281

AngelLM, 2016-12-29:
Wow! I have been a little bit offline in this issue, I really like the several solutions you have been talking about!
I saw that as5045 has a step size ~ 0.088... awesome! Its kinda expensive but I think it deserves the money. Keep me informed! :)

saeugetier, 2017-01-14:
http://www.distrelec.de/de/winkelsensor-qfn-28-ic-haus-ic-mh-qfn28/p/11039539
This chips seems to be a bit cheaper, but still expensive.

saeugetier, 2017-01-14:
As you can see in the datasheet of the  iC-MH http://www.ichaus.de/upload/pdf/MH_datasheet_C2en.pdf the supported resolution is 12bit (4096 steps per 360 degree). But the accuracy is lower. It depends on the quality of the magnetic target. The nonlinearity (interpolation error) can be reduced by calibration.

AngelLM, 2017-01-16:
Have you seen [uStepper project](http://ustepper.com/shop/home/9-ustepper-premium-kit.html)?
It is licensed under CC-BY-NC and all data of the project is available in its [GitHub repository](https://github.com/uStepper/uStepper)

saeugetier, 2017-01-16:
I know that project. I looked in the schematic. They are using an AS5600 which seems to be quite cheap while having an resolution of 12bits.  I saw this chip on DigiKey for 3€ each @10pieces.
I think that using a feedback for the steppers could result a small improvement. I would be better to have the feedback directly in the joint. In that case a custom feedback electronic has to be designed.

AngelLM, 2017-01-16:
@saeugetier I was thinking about it and makes sense to have the feedback directly in the joint as you said. For hinge joints that could be "easy" to install, but for pivot joints that could be trickier. Also, the last 2 joints would be even harder.
In other hand, having the feedback from motors would ease this job, but due to mechanical reductions we will lost the "absolute" feedback. (Most motors have to turn >360º to do a complete joint revolution).
I'll think about how link a sensor to the pivot joints.
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
AngelLM, 2017-01-17:
@Danny-VdH long time ago I thought about using potentiometers to get the feedback. I just want to share with you my experience. I used low-cost potentiometers (maybe that was the problem) and I tested them before including in the design. Using an oscilloscope I found that the signal provided by them wa pretty noisy. I calculated how that noise would affect to the feedback and I got around ±2º of precision. Having 6 articulation the error is incremented to... 6 x (±2º) = ±12º at tool. That was why I decided in first place to to an Open-Loop control. I'm sure that your potentiometer won't give that curly signal, but if you have access to an oscilloscope you can test it :)

i-make-robots, 2017-01-17:
I have been playing with AS5045 sensors.  double hall effect, 4096
absolution positions (0.08deg/step).  So far they've been really difficult
to calibrate correctly.  In theory when i get them working right then it
will be a single sensor unit that can be used all over many arms and other
robots.  https://www.instagram.com/p/BO79B5njnhU/

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

--
Dan Royer, Owner, Marginally Clever Robots
<https://www.marginallyclever.com/>
Ph: +1 (604) 259-9564
Mo: +1 (604) 916-2281

saeugetier, 2017-01-17:
For potentiometer and magnetic encode you can say that resolution and accuracy are different things. The resolution can be 12bits, but due nonlinearities the accuracy could be e.g. >1°.
For the magnetic encoder an accurate magnet is needed. The size of the north and south pole has to be equal. That's not an easy task. Most of the cheap magnet stores from internet have crappy quality. ASM sells its own magnets. I would recommend using them. The other point is that the magnet has to be placed exact in the middle of the chip. Even though the placing and the magnet are perfect, the resolution will not be the same as accuracy. With help of calibration the accuracy could be improved. But calibration is not an easy task. You will need some kind of reference system.
I think that the accuracy of the robot could be improved by a feedback system. But you should not expect too much...

saeugetier, 2017-02-21:
I saw this cheap encoder on eBay. Maybe it is worth to take a closer look at?

http://www.ebay.com/itm/600P-R-DC-5-24V-6mm-Incremental-Rotary-Encoder-AB-2-phase-Shaft-0-20KHz-NEU/272374834541

Danny-VdH, 2017-02-21:
I did a test with a potentiometer to get the position in a init fase and check every 100 ms to see if a am lossing position while moving the stepper. I must say, it is realy good, cheap and reliable.
For the base movement a use a 10 turns 10K potentiometer. for the arm movements I tested it with a potentionmeter with a hollow shaft. Most of the time it's just for starting up the robot from a power shutdown. I don't have to home my robot positions anymore. :-) Now I'm going to test a mini arduino build into one of the arms and connect all my axis except the base analog on it. Then I'm going to send all data through serial communication to my main controller. I just need 4 wires in my slipring to communicate and power between my main controller. I'm using a slipring between base and the other parts of the robot and this is working very good. Look at my hackaday page to see the photos.

i-make-robots, 2017-02-21:
@Danny-VdH what's your HAD.IO page url?

Danny-VdH, 2017-02-21:
closed loop is another story to do it with potentiometers, but for starting up and knowing your position it is good enough. I don't do anything with my steppers when it stays between 1° tollerance. If I didn't have any obstruction I totally stay working on the stepper counts, it's only when the difference is out of range I rehome my position to the actual potentionmeter position.

Danny-VdH, 2017-02-21:
It's also a good system to check when there was an obstruction to stop the movements of the robot and force it the restart the robot.

Danny-VdH, 2017-02-21:
[https://hackaday.io/projects/hacker/145041](url)

Danny-VdH, 2017-02-21:
I'm going to make a software that reacts when a moving to a particular speed it has to make a distance, if this distance is taking to long I got a following error.

AngelLM, 2017-09-27:
It seems like Danny-VdH made a nice and affordable solution here: https://hackaday.io/project/16665-thor-robot-with-addons-and-gui/log/64709-thor-v202-with-feedback-sensors#
My bad for not noticing it before!
Sounds like solved!

Closed 2017-09-27.

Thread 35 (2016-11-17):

Control PCB update

AngelLM, 2016-11-17:
I made the Control PCB as a prototype and it worked well. It's necessary to update it in order to add some features and by the way design it to produce it professionally instead of making it with a CNC.

AngelLM, 2016-11-17:
Working on this!

AngelLM, 2016-12-12:
Redesign done, waiting for test to close this :+1:

AngelLM, 2016-12-19:
Merged on 7995187, not tested yet.

AngelLM, 2017-08-08:
Tested and working months ago! :laughing:
Minor bugs found will be fixed in the next version

Closed 2017-08-08.

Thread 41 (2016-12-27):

Cooper plate?

i-make-robots, 2016-12-27:
In bill of materials

AngelLM, 2016-12-29:
Hi! The cooper plate is needed if you make the first version of Control PCB.
I'll upload it soon with the materials of the new version of the Control PCB :)

Regards!

i-make-robots, 2016-12-29:
I get it. Should be spelled "copper".

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

AngelLM, 2016-12-30:
Fixed on commit 4d9601d
Thanks for the correction!

Closed 2016-12-30.

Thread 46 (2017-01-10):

Where does the logic lie?

lizixroy, 2017-01-10:
Hi @AngelLM

First of all, thank you very much for creating Thor, very impressive and helpful indeed.
I have been looking for some control logic (or maybe inverse kinematics solver, etc.) and hardware drivers, but I can't seem to find any actual code in this repository, there are tons of nice assets (CAD files) but the actual programs are no where to be found.

Where do you keep your logic? Maybe this is how a robotic project is typically organized, but as a software developer making his first foray into this field, I am confused by it.

The hardware design side of things is tremendously interesting, but can you write more about the software aspects of the project?

Thank you very much.

BR,
Roy

AngelLM, 2017-01-10:
Hi @lizixroy !

Thanks for your kind words :)
For the control of the motors I made a modified version of GRBL. You can find the Thor's Firmware in [this repository](https://github.com/AngelLM/grbl). I have not developed GRBL, that's why I thought that this modification should be a fork from the original one.

Right now I use GRBL, flashed inside an Arduino Mega, to control 7 steppers using forward kinematics. I have solved the inverse kinematics, but when I tried to put it into the GRBL inside the Arduino Mega didn't work. Probably the processor was not powerful enough.
There are users at Hackaday community who are developing awesome software for Thor, I recommend you to take a look to [Danny's posts ](https://hackaday.io/project/16665-thor-robot-with-addons-and-gui#menu-logs)

Hope it helps, feel free to ask anything you want to know :)

williamleferrand, 2017-01-14:
Hi there,

Thanks @AngelLM for your work - I'm building a Thor too; my goal is to make it remote-controllable via the internet and to pair it with a printer so that remote users can print+assemble simple designs.

I looked at Danny's UIs and I'm probably going to do a web based version of his manual UI in the coming days - I'll share it on github!

AngelLM, 2017-01-14:
Hi @williamleferrand !
That would be an amazing project! Keep me informed :)

AngelLM, 2017-01-14:
As the main question was solved, I'm closing the issue.

williamleferrand, 2017-01-14:
@AngelLM will do! did you get my email btw?

AngelLM, 2017-01-15:
@williamleferrand Let me check it right now!

Closed 2017-01-14.

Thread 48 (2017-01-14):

Readme: Printer Requirements

saeugetier, 2017-01-14:
Could you mention in the readme which kind of printer was used to print Thor, please?
Is 200x200x180 enough space to print all parts?

williamleferrand, 2017-01-14:
It is if you use the stls that are in stl/modifications (for printing bits of Art2 & the base). Otherwise according to the hackaday post,

"The most important fact is that the largest printable piece designed is 290mm of depth and I recommend to print it lied flat, that's why I suggest using a printer that has at least 290mm of printing length on one of its horizontal axis."

AngelLM, 2017-01-15:
Thanks @williamleferrand !
@saeugetier , as William said you can print the modificated parts with your printer. I'll add this question to the FAQ.

Closed 2017-01-15.

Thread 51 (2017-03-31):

Parts inside Art56 casing hard to access

b-adkins, 2017-03-31:
I like how everything is a tight fit - it uses the space well. However, I think making it a two-piece clamshell (splits along a "U" down the axis) would make it much easier to access.

DanielYWoo, 2023-12-17:
Can you have an example to illustrate with FreeCAD or OpenSCAD?

DanielYWoo, 2023-12-27:
I am not sure what you mean exactly but I feel somehow similar. Today, I tried to add 3 wires for pressure sensor on the clipper. It's very difficult to do that and I have to disassemble a lot of things. e.g., there are screws in the inner sides of articulation 1. If we can screw from the outer sides, it will be much easier.

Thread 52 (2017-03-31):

Art 4 Transmission Column unnecessarily tight fit for bearing

b-adkins, 2017-03-31:
The smallest extra print material will mean the bearing does not fit down the central shaft and can be damaged by inexperienced makers trying to force it. Instead of a single inner radius that is the exact radius of the bearing, there could be a loose fit for almost all the shaft except the final place where the bearing would continue to fit snugly. As there is a screw holding the bearing in, there is no danger of the bearing falling out.

AngelLM, 2017-04-03:
Hi @b-adkins ,
I think I don't get the point of your idea, could you add a diagram or something like that to help me to understand it?
Thanks! 😄

Closed 2017-08-08.

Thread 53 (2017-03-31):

Art56 Small Gears do not fit all variations of GT2x40 pulleys

b-adkins, 2017-03-31:
It's a clever use of a set screw to attach the pulley to the 3d printed gear! However, it looks like the GT2 standard doesn't apply to the set screws. The pulleys I ordered ended up having 4mm (not 3mm) set screw holes that do not line up with the hole in the gear.

So I used hot glue. I'll see if it can handle the torque.

AngelLM, 2017-04-03:
Hi @b-adkins ,
I didn't knew it, I assumed that it was standard. Anyway, you can adjust the 3D model to fit to your needs, if you need help with the modification of that 3D model tell me ;)
Also, I'm interested in knowing if the hot glue fix work with a load of 750g!

AngelLM, 2017-05-09:
@b-adkins how it's going? the hot glue worked?

Closed 2017-08-08.

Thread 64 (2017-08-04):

cinematic motion algorithm

mkeyno, 2017-08-04:
hi, sorry to open ticket for my question , but actually I'm little lost to find the methods can convert input location (Cartesian , polar) to the optimized cinematic motions of each axis? for example how to defined the  best path from  A to B coordinates and how it converted  the cinematic  motion for each axis? what is the optimization function & type ?how to define cinematic motion parameters of specific arms? I really appreciated for your hint

i-make-robots, 2017-08-04:
what do you mean when you say "cinematic" motion?

i-make-robots, 2017-08-04:
Thor does not, at this time, afaik, have a motion planning software that would, say, let you plot lines in space and then move the arm to meet those points, like this: https://www.youtube.com/watch?v=AO57-fZUWho

mkeyno, 2017-08-05:
sorry I mean  kinematic , you know, every robot has its own physical parts and degree of freedom so to define path between two given points we need the calculate some  dynamic equations to find this patch and other parameters(like velocity and acceleration ) , however there is no unique path between two given points , thus some optimization algorithm applied to find the best and smooth path , I saw couple of repo use the CNC planner code to implemented this path but not find yet the path optimization algorithm

i-make-robots, 2017-08-05:
Frequently the shortest path is taken.  I know the number of steps each motor must take and the speed of the slowest motor.  I then step all motors so that they arrive simultaneously at the destination.  There are times when this solution is bad - it does not take into account impossible geometries or singularities BUT if you can avoid them it works great.

i-make-robots, 2017-08-05:
sorry, to calculate the kinematics is how you get the number of steps of each motor.  I have some examples in https://github.com/MarginallyClever/Robot-Overlord-App/ for 4 and 5 DOF arms.  Maybe that will help?  I don't remember atm if THOR is supported yet, but I'd like to see it happen.

AngelLM, 2017-08-07:
Hi! Sorry for the late reply.
Currently Thor moves using Forward Kinematics (at least mine). The calculations involved in the movement are responsibility of the firmware (GRBL). At this time there is not implemented neither a control using Inverse Kinematics nor movement optimization.
If it helps here it's the [solution for the Forward Kinematics](https://hackaday.io/project/12989-thor/log/43941-forward-kinematics). And here the [solution of the Inverse Kinematics](https://hackaday.io/project/12989-thor/log/44018-inverse-kinematics) of Thor.
Also, @Danny-VdH were developing a GUI to control robotic arms. You can chek it out too ;)

Hope it helps!

i-make-robots, 2017-08-07:
If I have the relative distance between each joint in the system and an simplified STL of each THOR part I could add it to Robot Overlord.  Then it would send FK commands to the arm, much as it does with my other robots.  If that's of interest to you, make it so.  I could get it implemented before the end of August.

AngelLM, 2017-08-07:
@i-make-robots That sounds good! I think that you have all the distances you need in [this image](https://github.com/AngelLM/Thor/blob/developer/doc/ThorDimensions.png).

i-make-robots, 2017-08-07:
I explained myself badly.  I need an STL of each section - the base, the
shoulder, the bicep, the ulna, the wrist.  For each part, I need the origin
of the part to be at the point of rotation or, in the case of the base, at
the world origin.  For each part I also need a measurement of the distance
from the origin to the axis of rotation of the next part.  In the case of
the base, I need to know how far up to reach the point where the shoulder
rotates.  the shoulder origin would be at that spot, and the relative
distance from there to the rotation point of the bicep, and so on.  Does
that make more sense?

I can spend hours monkeying around trying to fix it in software but I've
got very limited time. I'm hoping we can help each other, here.

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

--
Dan Royer, Owner, Marginally Clever Robots
<https://www.marginallyclever.com/>
Ph: +1 (604) 259-9564
Mo: +1 (604) 916-2281

AngelLM, 2017-08-08:
Hi @i-make-robots
I just upload the [STL files of each articulation](https://github.com/AngelLM/Thor/tree/developer/stl/FullArticulations)
Also, the distances are the following, understanding global positions as the XYZ coordinates of the space and the local position as the XYZ coordinates of the piece.

- **Base**
    - Global position (X,Y,Z): 0,0,0
    - Rotation axis: None
    - Rotation axis local position: None
- **Articulation 1**
    - Global position (X,Y,Z): 0,0,49
    - Rotation axis: Z
    - Rotation axis local position: 0,0,0
- **Articulation 2**
    - Global position (X,Y,Z): 0,0,137
    - Rotation axis: Y
    - Rotation axis local position: 0,0,65
- **Articulation 3**
    - Global position (X,Y,Z): 0,0,295
    - Rotation axis: Y
    - Rotation axis local position: 0,0,64
- **Articulation 4**
    - Global position (X,Y,Z): 0,0,377,5
    - Rotation axis: Z
    - Rotation axis local position: 0,0,0
- **Articulation 5&6**
    - Global position (X,Y,Z): 0,0,510
    - Art 5 Rotation axis: Y
    - Art 5 Rotation axis local position: 0,0,47
    - Art 6 Rotation axis: Z
    - Art 6 Rotation axis local position: 0,0,0

I don't really know if the STL of the last 2 articulation will work (because of coupled movements). Probably splitting it into 2 pieces (the column + gears for the 5th and the rest for the 6th) would make the work. I'll do it now, just in case.

AngelLM, 2017-08-08:
Split done.
The new distances would be:

- Articulation 5
    - Global position (X,Y,Z): 0,0,510
    - Art Rotation axis: Y
    - Art Rotation axis local position (X,Y,Z): 0,0,47
- Articulation 6
    - Global position (X,Y,Z): 0,0,610.431
    - Art Rotation axis: Z
    - Art Rotation axis local position (X,Y,Z): 0,0,0

i-make-robots, 2017-08-08:
are you sure about articulation 2, distance 65?  looking at the parts
together it looks more like 85 or 90.

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

--
Dan Royer, Owner, Marginally Clever Robots
<https://www.marginallyclever.com/>
Ph: +1 (604) 259-9564
Mo: +1 (604) 916-2281

i-make-robots, 2017-08-08:
ok, I have the model displaying after adjusting the origins.  You'll
probably want to split the gripper tool from the wrist component.  Biggest
reason so you can animate the gripper action.  I'll take some more time
later this week to implement FK.

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

--
Dan Royer, Owner, Marginally Clever Robots
<https://www.marginallyclever.com/>
Ph: +1 (604) 259-9564
Mo: +1 (604) 916-2281

i-make-robots, 2017-08-08:
aaaand now i have FK working, kind of.  Fingers crossed I can get IK
working just as easily.

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
>>> Split done.
>>> The new distances would be:
>>>
>>>    - Articulation 5
>>>       - Global position (X,Y,Z): 0,0,510
>>>       - Art Rotation axis: Y
>>>       - Art Rotation axis local position (X,Y,Z): 0,0,47
>>>    - Articulation 6
>>>       - Global position (X,Y,Z): 0,0,610.431
>>>       - Art Rotation axis: Z
>>>       - Art Rotation axis local position (X,Y,Z): 0,0,0
>>>
>>> —
>>> You are receiving this because you were mentioned.
>>> Reply to this email directly, view it on GitHub
>>> <https://github.com/AngelLM/Thor/issues/64#issuecomment-320927692>, or mute
>>> the thread
>>> <https://github.com/notifications/unsubscribe-auth/ABZYhh0SQm-QViQZNVUfUExYhktaBzpUks5sWEW9gaJpZM4OtoJJ>
>>> .
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

--
Dan Royer, Owner, Marginally Clever Robots
<https://www.marginallyclever.com/>
Ph: +1 (604) 259-9564
Mo: +1 (604) 916-2281

i-make-robots, 2017-08-08:
Right, IK looks to be mostly working.  I've done the first 95%, please
contribute whatever you can to make it even better.

https://www.instagram.com/p/BXi0Ci4gLqb/

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
>>> are you sure about articulation 2, distance 65?  looking at the parts
>>> together it looks more like 85 or 90.
>>>
>>> On Tue, Aug 8, 2017 at 4:25 AM, AngelLM <notifications@github.com>
>>> wrote:
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
>>> --
>>> Dan Royer, Owner, Marginally Clever Robots
>>> <https://www.marginallyclever.com/>
>>> Ph: +1 (604) 259-9564 <(604)%20259-9564>
>>> Mo: +1 (604) 916-2281 <(604)%20916-2281>
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

--
Dan Royer, Owner, Marginally Clever Robots
<https://www.marginallyclever.com/>
Ph: +1 (604) 259-9564
Mo: +1 (604) 916-2281

AngelLM, 2017-08-08:
You are right! Is Z 95mm

El 8/8/2017 17:41, "Dan Royer" <notifications@github.com> escribió:

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

AngelLM, 2017-08-08:
I saw it! Awesome work!
Expect some contributions and feedback from my side! :)

Closed 2021-08-09.

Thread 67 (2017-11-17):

ART2 BodyA that meshes with two gears always slipping. Bad fit?

martinbarr, 2017-11-17:
Hi Angel,

After some serious testing and trials in getting the robot arm to move, it worked for a little while then I started having serious slipping issues. I watched and saw the ART2 A arm flex too much at the bottom where the only support it has are the two pins on the top motor and the ART2 Union. Not sure how everyone else has got on with this or if they have also had issue too. Would love to know. I will look to try and solve my particular issue,

Thanks in advance

Martin Barr

martinbarr, 2017-11-22:
Hi All,
I logged this issue and carried on investigating.

After several attempts to correct I found this issue that I thought I would share. Maybe I missed the depth that the pulley wheel should be. I did a sketch to show what I did.

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

AngelLM, 2017-11-24:
Hi @martinbarr !
Do you think that it's possible that the pin in the opposite side is not longer enough? This could be causing this articulation to be a bit loose.

Other reason could be a bending issue... Maybe the Articulation 2 is not acting as rigid piece and the lower parts are bending outwards... I don't really know.

AngelLM, 2018-04-25:
Did you solved it?

Closed 2019-01-31.

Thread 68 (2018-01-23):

Some dimensions that may be wrong

diegotrap, 2018-01-23:
Hello everyone,

I am printing a complete set of Thor's printed parts and while testing the fit of the different parts with bearings, bolts, etc I have noticed some dimensions that make assembly very hard or require the printed part to be postprocessed (sanded, drilled, etc.).

This notes refer to the DesignUpdate branch, which is the one that I am using.

These are the ones that I have caught by now:

* **Gripper**: every bolt head pocket have a radius of 2.7mm. M3 DIN912 bolts have a 2.75 nominal radius, so the heads won't fit. Other bolt head pockets in Thor have 2.95mm radius. Changing the Master bolt head won't be enough since not every head references to the entity, it has to be done one hole at a time.
* **BaseBoxBody**
    * fan bolt head pocket have a radius of 2.7mm. Changing the Master bolt head won't be enough since not every head references to the entity, it has to be done one hole at a time.
    * insert holes are too big for 5mm inserts. Holes should be at least a couple of tenths smaller to hold the insert.
* **Art56GearPlate** inner bore for a 625 bearing is only 16mm in diameter, some slack has to be included to be able to push the bearing in.
* I find **BearingFix** parts hard to get into their pockets, I would reduce the diameter by some tenths.
* **BearingPlug** won't fit in it's hole. Maybe is meant to be printed in flexible material?

Other stuff:
* This is a FCSTD1 file that has made his way into the repo: https://github.com/AngelLM/Thor/blob/DesignUpdate/freecad-src/Art2SideCover.FCStd1

Sorry not to be able to change it myself, my set of files is already very different from the source files and my git knowledge is not very extensive.

I'll post here if I spot more things like these.

Diego.

AngelLM, 2018-01-25:
Thanks Diego for the feedback! I'll check it ;)

AngelLM, 2018-01-25:
Okay, this are the changes I did until now
- **Gripper**: Bolt heads modified from 2.7mm to 2.95mm
- **BaseBoxBody**: Bolt heads modified from 2.7mm to 2.95mm, holes for the inserts modified from 5mm to 4.8mm.
- **Art56GearPlate**: Inner bore modified from 16mm to 16.2mm

About the *BearingPlug* piece: it was not designed to enter completely into the hole, only a bit,to prevent the bearing balls from pop out the rail. Maybe the plug piece diameter is larger than it should be. I'll check it.

Finally, *BearingFix* is a complicated piece to modify as it is already small. The problem is only the diameter or it is alse the fixing tabs?

AngelLM, 2018-07-04:
Solved and merged!

Closed 2018-07-04.

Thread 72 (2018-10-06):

Looking for a Print Inventory List, and unit scaling on STLfiles.

AlexanderPeters, 2018-10-06:
Hi, could you please let me know where I can find a Bill Of Materials that includes the quantity of each number of 3D printed component that need to be printed. Additionally can you please let me know if the .stl files are scales in in, mm, or cm.

-Thanks

AngelLM, 2019-02-07:
Hi @AlexanderPeters ,

Currently there is not a BOM including the quantity of printed pieces. I'll do it soon. Meanwhile you can download the FreeCAD assembly file and check it.
The unit used on the STL files, and every 3D file in this repository is mm.

Thank you for your suggestion!

AngelLM, 2021-08-09:
In the new [Thor's website](http://thor.angel-lm.com/) I've added a 3D Printing Guide with the ammount of pieces needed of each model and the recommended settings to print them all.

Closed 2021-08-09.

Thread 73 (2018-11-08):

Stepper Motor Gearbox/Planet drive

KenwoodFox, 2018-11-08:
I cant seem to find that gear ratio/model number for the #2 articulation, help?!

AngelLM, 2019-01-31:
You have a List Of Materials, including links to that stepper motor in the wiki page [Component List](https://github.com/AngelLM/Thor/wiki/Component-list).

Closed 2019-01-31.

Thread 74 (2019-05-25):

Current software to use

LoLo2207, 2019-05-25:
Hi, I have an Ultratronics Pro board but I don't know what firmware to use. Is there any firmware available for this board?

If there isn't, what board can I use to easily wire and control the arm besides the custom PCB?

DavidVives, 2019-09-09:
Dear LoLo2207, did you find any board and firmware that works?
Many thanks and best regards

AngelLM, 2021-08-09:
As far as I know, currently there is no other option than Arduino Mega + [ThorControlPCB](https://github.com/AngelLM/ThorControlPCB/) with the [GRBL Thor version](https://github.com/AngelLM/grbl)

Closed 2021-08-09.

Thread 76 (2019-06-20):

Alimentación del servo de la articulación 6

lisergio, 2019-06-20:
En primer lugar me disculpo por escribir en castellano ( Traducción después con google)...

Estoy montando la electrónica "ControlPCB" siguiendo el esquema, y me he fijado en que el servo va conectado directamente sin ningún regulador de tensión... por lo que imagino que lo estamos alimentando con los 5v de la placa Arduino Mega, es correcto??

Gracias.
Gran trabajo,

estoy esperando a que me lleguen todas las piezas mientras imprimo todo...

Traducción :

First of all I apologize for writing in Spanish (Translation later with google) ...

I am mounting the electronics "ControlPCB" following the scheme, and I noticed that the servo is connected directly without any voltage regulator ... so I guess we are feeding it with the 5v of the Arduino Mega board, is it correct? ?

Thank you.
Great job,

I'm waiting for all the pieces to arrive while I print everything ...

VictorLamoine, 2019-06-21:
Do NOT connect anything that sources power to an Arduino pin, you will most probably fry the Arduino.
Read this: https://arduino.stackexchange.com/questions/88/is-there-a-limit-on-how-much-current-a-pin-can-sink.

lisergio, 2019-06-21:
Gracias, eso lo entiendo.

pero en el esquema del circuito no hay ningún regulador de 5v, por lo que el servo se alimenta de la placa Arduino.

Thanks, I understand that.

but in the circuit diagram there is no 5v regulator, so the servo is powered by the Arduino board.

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

hay que añadir una alimentación de 5v solo para el servo?
should we add a 5v power supply only for the servo?

gracias
thanks

AngelLM, 2019-06-24:
Hola @lisergio
Como bien dices, el cable de alimentación del servo va conectado a los pines que has marcado en las imágenes. Las salidas de VCC y de 5V auxiliares están conectadas con la salida de 5V de Arduino (y como este ya incorpora su propio regulador de tensión no hay que añadir nada más).
En resumen, puedes conectar el servo directamente a la placa sin problemas.
¡Espero haberte ayudado!

Hi @lisergio, as you said, the servo's power wire is connected to the pins that you marked in the images. The VCC and 5V aux outputs are connected to the Arduino's 5V Output (and as it already has its own power regulator, there is no need to add anything to the circuit).
To sum up, you can connect directly the servo to the board without any problem.
Hope it helps!

lisergio, 2019-06-25:
Eso era justo lo que quería saber, muchas gracias!!
La cuestión es que voy a usar un servo con piñones metálicos (20kg , 0,15seg) y el consumo es un poco alto...
Así que tendré que colocar una fuente aparte de 5v solo para el servo y así  proteger el regulador de la placa arduino.

That was just what I wanted to know, thank you very much !!
The point is that I'm going to use a servo with metallic pinions (20kg, 0.15sec) and the consumption is a bit high ...
So I will have to place a separate source of 5v only for the servo and thus protect the controller from the Arduino board.

Closed 2019-06-25.

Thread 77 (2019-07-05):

Duda en el montaje / Doubt in the assembly

lisergio, 2019-07-05:
hola de nuevo...
he empezado el montaje de thor, y tengo una duda...
las siguientes piezas forman parte del mismo montaje?
Art3TensionerBody.stl
Art3TensionerPulley.stl
2	×	MF84ZZ Bearing
2	×	14mm x ∅5mm Rod

el paso del rodamiento es de 4mm, y la varilla es de 5mm, por lo que no encaja.

Hello again...
I have started the assembly of thor, and I have a doubt ...
the following parts are part of the same assembly?
Art3TensionerBody.stl
Art3TensionerPulley.stl
2 × MF84ZZ Bearing
2 × 14mm x ∅5mm Rod

the bearing pitch is 4mm, and the rod is 5mm, so it does not fit.

AngelLM, 2019-07-05:
Hola @lisergio
Todas esas piezas forman parte del mismo montaje, pero el diámetro de las varillas de 14mm de largo debería ser de 4mm en lugar de 5mm. En la [lista de materiales ](https://github.com/AngelLM/Thor/wiki/Component-list) aparece así, ¿lo he publicado mal en otro lugar?
¡Un saludo!

Hi @lisergio
All of that pieces are part of the same assembly, but the diameter of the 14mm length rods should be 4mm instead of 5mm. As it appears in the [list of materials](https://github.com/AngelLM/Thor/wiki/Component-list) Have I published it wrong somewhere?
Regards!

lisergio, 2019-07-05:
en la lista de materiales de hackaday.io pone que son de 5mm

in the hackaday.io list of materials says that they are 5mm

Gracias!!! Aclarado!!

AngelLM, 2019-07-05:
Corregido en el post de Hackaday, gracias por darte cuenta!

Fixed in the Hackaday post, thanks for find it out!

Closed 2019-07-05.

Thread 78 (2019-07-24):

Servo not move... / El servo no se mueve

lisergio, 2019-07-24:
hola de nuevo, ya tengo varias articulaciones montadas, y he empezado a probar la electronica, pero tengo un par de problemas... todos los motores se mueven, aunque no todos en los grados que deberian ( he usado tu configuracion de GRBL ) , será cuestion de modificar los pasos/mm , pero la pega es, que usando Asgard, la pinza, no rota, el boton de la articulacion 5 y de la 6 hacen lo mismo, y por ultimo el servo no hace nada...
he probado con otro por si a caso y tampoco funciona, pero si hace un pequeño movimiento al iniciar el sistema.

Gracias!

hello again, I already have several assembled joints, and I have started to test the electronics, but I have a couple of problems ... all the motors move, although not all in the degrees that they should (I have used your GRBL configuration), it will be a matter of modifying the steps / mm, but the glue is, that using Asgard, the clamp, does not rotate, the button of the articulation 5 and the 6 do the same, and finally the servo does nothing ...
I've tried another one just in case and it doesn't work, but it does make a small movement when starting the

Thanks

lisergio, 2019-07-26:
He solucionado el problema del servo, ya se mueve, era un problema del conector... pero no me hace todo el recorrido, donde se puede ajustar?

en cuanto al giro del gripper, sigue sin funcionar usando Asgard  ( enviando un Gcode,Y90 Z-90 si funciona)

I have solved the servo problem, it is already moving, it was a connector problem ... but it does not make me the whole route, where can it be adjusted?

As for the rotation of the gripper, it still does not work using Asgard (sending a Gcode, Y90 Z-90 if it works)

mnc5, 2019-07-27:
unsubscribe   please

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

Closed 2019-07-27.

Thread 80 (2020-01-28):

Servo Motor - PORTG0 (pin41) no PWM output

celoke, 2020-01-28:
Hi,

Built the board, loaded the firmware on. All commands work except M3 to control the servo. Probed digital pin 41 no PWM output, is there something I'm missing? Please help

celoke, 2020-01-28:
OK, got it to work, swapped to digital pin45 using OC5B instead

AngelLM, 2021-08-09:
I'm sorry to be this late, but can you share how you solved it?
The original idea was to wire the pin that should go to the pin 41 to the pin 7 instead (as the 41 is digital and not PWM). This was because I made an mistake during the PCB design.
Did you wire the STool Signal to the Digital 45 pin? Is that pin PWM?

Thanks!

Closed 2022-05-15.

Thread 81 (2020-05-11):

Modificar Asgard

lisergio, 2020-05-11:
Buenas de nuevo!!!
Después de mucho tiempo, he retomado el proyecto... y he pensado usar  una raspberry pi con pantalla táctil para controlar a thor, pero al instalar asgard en la raspberry, resulta que no cabe en la pantalla, que tiene una resolución máxima de 800x400..
Hay alguna manera sencilla de modificar el gui.py para poner solo lo básico?
El botón de conectar, y los sliders de las articulaciones, y de paso, eliminar el boton “go” y que envie el gcode directamente al mover el slider...
gracias!!!!

AngelLM, 2021-08-09:
Hi! The development of Asgard is being made in its own repo: https://github.com/AngelLM/Asgard
I'm gonna close this issue, but I have taken note of this for future designs.

Thanks! :)

Closed 2021-08-09.

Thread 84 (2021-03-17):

5mm (diameter) rods do not fit on 625ZZ bearings and similar issue with motor shaft and pulley

emlachapelle, 2021-03-17:
In the process of building Thor I've run into the issue that the 5mm (diameter) rods do not fit in the 625ZZ bearings that were on the bill of material... Similarly, the GT2-6 Timing Belt Pulley 20T (inner bore of 5mm) does not fit at all on the shaft of the Stepper Motor 17HS13-0404S-PG5 also provided in the bill of material.

Would it be possible to know what you used instead of these components to ensure a proper fit? Thanks!

AngelLM, 2021-08-09:
It should fit as the inner bore has 5mm diameter... I used some spare threaded M5 rods that I had at home in case it helps you.
About the Pulley issue, has your motor a 5mm diameter shaft? I don´t know why but there are models named the same with 6mm diameter shaft. In case it is and still doesn´t fit all I can recommend is to file the inner bore of the pulley a bit, or make the hole bigger with a drill

Closed 2021-08-09.

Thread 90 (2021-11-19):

Payloads

x0rium, 2021-11-19:
Hi! Does the project support laser engraving or 3d printer heads connection? I found only cnc mill head connection sample.

AngelLM, 2021-11-20:
Hello! As far as I know no one has mounted a laser engraving or a 3D printer nozzle to Thor yet, but it sounds very interesting!
In terms of mechanics, you could design a gripper for the tool you want to mount based on the Art56Interface piece.
As for the electronics, the current control board as a digital PWM output (f.e. to control a laser) and a spare stepper driver that could control the motor of a extruder... So I don't think it would be impossible to achive, but it would be a very dedicated job :)
Just curious, where have you seen that cnc mill head connection example?

Best regards!

x0rium, 2021-11-23:
Thx for answer :)
https://youtu.be/_EjADbIS9GQ
I think it's will be grate to use roboarm as universal mechanics with functional heads. For example to making pcb
1) textolite panel with photoresist film illuminated by an ultraviolet laser
2) with the help of a manipulator it is transferred into a bath with a chemical composition to remove the film
3) drilling holes
4) pick and place elements
5) move to hot plate
6) testing
Sounds very cool :)

x0rium, 2021-11-26:
https://github.com/madl3x/x-scara

Closed 2021-11-27.

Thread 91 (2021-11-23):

Confusion on PCB circuit

DigeshC, 2021-11-23:
Hi! We are planning to build Thor but had some confusion regarding the PCB circuit. We were confused on what P1...P8 were on the circuit diagram and how they are connected in the circuits. Thank you so much!

AngelLM, 2021-11-24:
Hello!

The Control PCB is pretty similar to the RAMPs 1.4 and this feature is a legacy of this board.
P1...P8 are groups of 3 columns of 2 male pins. One pin of each column is connected to 5V and the oposite pin is connected to the driver's microstepping pin (MS0, MS1 and MS2 respectively (See [PCB Control Schematic](https://github.com/AngelLM/ThorControlPCB/blob/master/Docs/ControlPCB-Schematic.pdf)).
MS pins are used to configure the microstepping by setting the pin to high level (5V), shortcutting the columns using jumpers (See [B section of this image](https://www.researchgate.net/publication/339101918/figure/fig4/AS:867963263528965@1583949976723/Wiring-of-XYZ-System-A-RAMPS-14-shield-top-and-Arduino-Mega-bottom-B-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)).
Depending on which columns have been short-circuited the configuration will be different (See [microstepping configuration table](https://i.stack.imgur.com/vN7JL.png)]
After setting the jumpers, you can place the stepper driver on top of them.

Hope it helps!
Ángel

DigeshC, 2021-12-17:
Hello!
Thank you so much for your explanation. It cleared up our confusion.

Closed 2021-12-17.

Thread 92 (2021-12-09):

Arduino Code to Control Stepper Motor

hwu2023, 2021-12-09:
Hello,

Instead of using a PCB, I am building the firmware configuration on a breadboard. I am having trouble controlling the motors with GRBL. In the grbl file, is there a place that defines what each Arduino pin does?

Thank you!

Closed 2021-12-09.

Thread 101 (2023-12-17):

Endstop on PS1

DanielYWoo, 2023-12-17:
PS1 in the [diagram](http://thor.angel-lm.com/wp-content/uploads/2021/08/WireDiagram-v1_0.png) connects to an infrared speed sensor as an endstop. How does it work? I am kind of confused because I think we need to know the min and max positions on both ends of the opto disk. I see there is a gap in the opto disk, I am not sure, do we use the gap for min/max detection and homing?

DanielYWoo, 2023-12-17:
And PS6 connects to a 3-pin mech switch as the endstop, I guess a 2-pin switch works too if we enable the built-in pull-up resistor on the Arduino board, right? That saves a wire.

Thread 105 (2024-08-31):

Questions about rods specification

nomorewzx, 2024-08-31:
Hi, I am now trying to figure out the [BOM list](https://github.com/AngelLM/Thor/wiki/Component-list)

I see the 2 rods with specification:

1. Length 102mm, Diameter 5mm
2. Length 128mm, Diameter 5mm

However in the Aliexpress link of the rods, I found that the maximum length of the rods with 5mm is actually 100mm.

I tried search other rods in Aliexpress and could not find the 5mm-rods with length 102mm or 128 mm.

My questions are: Does 100mm x 5mm rods works as well? If not, is there updated rods link?

Thanks a lot

AngelLM, 2024-08-31:
Hello @nomorewzx !

First of all, I would recommend you to have a look at the [project website](http://thor.angel-lm.com), where you will find much more updated information, as the repository wiki is outdated.
That said, in the[ BOM section of the website](http://thor.angel-lm.com/documentation/bom/) you can find links to the sticks. Because the measurements required for the construction of Thor are very specific, you have to buy longer rods and cut them to the required length.
If you don't have the necessary tools, as the rods are of a very common diameter you may be able to find them at a local hardware store where they can help you with the cutting.

Finally, if you are going to embark on the construction of your own Thor, I would recommend you to join the [project forum](http://thor.angel-lm.com/forums/), where you can share your construction process, ask questions and see other users' doubts. We also have a [Discord server](http://thor.angel-lm.com/forums/topic/thor-discord-server/) for more direct communication.

Hope this helps!

Translated with DeepL.com (free version)

AngelLM, 2024-08-31:
Hello @nomorewzx !

First of all, I would recommend you to have a look at the [project website](http://thor.angel-lm.com/), where you will find much more updated information, as the repository wiki is outdated.
That said, in the[ BOM section of the website](http://thor.angel-lm.com/documentation/bom/) you can find links to the sticks. Because the measurements required for the construction of Thor are very specific, you have to buy longer rods and cut them to the required length.
If you don't have the necessary tools, as the rods are of a very common diameter you may be able to find them at a local hardware store where they can help you with the cutting.

Finally, if you are going to embark on the construction of your own Thor, I would recommend you to join the [project forum](http://thor.angel-lm.com/forums/), where you can share your construction process, ask questions and see other users' doubts. We also have a [Discord server](http://thor.angel-lm.com/forums/topic/thor-discord-server/) for more direct communication.

Hope this helps!

Closed 2024-08-31.

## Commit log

2015-04-23 Added FreeCAD files, Readme and By-sa image.
    [Thor.fcstd]
2015-04-26 Base fixed
    [Thor.fcstd]
2015-04-26 Base Bearing Anchors fixed, Articulation 1 and Articulation 1 anchors fixed
    [Thor.fcstd]
2015-04-26 Base motor fix1 applied, Base motor fix2 applied, articulation 1 fixed, screenshots added
    [Thor.fcstd]
2015-04-27 .step and .stl base files added
    [Thor.fcstd, art1-bearing-anchor.step, art1-bearing-anchor.stl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]
2015-04-27 Articulation 2&3 motors added. GT2 Motor pulley added.
    [Thor.fcstd]
2015-04-28 2x Articulation 1 body added. Testing shapes.
    [Thor.fcstd]
2015-04-28 2x Articulation 1 body added. Testing shapes. Updated
    [Thor.fcstd]
2015-04-29 Articulation 2 Body added
    [Thor.fcstd]
2015-05-03 GT2 Pulley Big Added, Pieces updated
    [Thor.fcstd]
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2015-05-24 Base & Articulation 1 modified
    [transm-pulley.stl]
2015-05-26 Base & Articulation 1 modified. Old .stl files removed.
    [art1-bearing-anchor.stl, art1-motor-coupler.stl, art1.stl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]
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2015-06-01 Articulation 1 motor fix modified
2015-06-01 Stl files added. Assembly pictures added.
    [art1-bot.stl, art1-motor-fix.stl, art1-motor-gear.stl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]
2015-07-08 Bearings fixed. Articulation 5&6 added. Articulation 4 modified. Articulation 2 & 3 updated.
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2015-08-05 gcode, step and stl folders & files removed
    [art1-bearing-anchor.step, art1-bot.stl, art1-motor-coupler.step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]
2015-08-10 Some parts updated, stl added
    [art1-body.stl, art1-bot.stl, art1-motor-gear.stl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]
2015-08-11 Art2-BodyB modified. New stl files
    [art2-bodyA-covercircle.stl, art2-bodyB-cover.stl, art2-bodyB-window.stl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]
2015-08-12 Art2 BodyA modified & stl added
    [art2-guide-prueba2.stl]
2015-08-12 Art2 BodyA modified, stl files added
    [art2-bodyA-cover.stl, art2-bodyA-window.stl, art2-bodyA.stl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]
2015-08-12 Bearing housing fixed
2015-08-13 stl of fixed part generated, art1 body fixed
    [art2-bodyA-window.stl, art2-bodyA.stl, art2-bodyB.stl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]
2015-08-13 New gears, fixed art5&6 parts
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2015-08-26 Art56 fix
    [prueba-interf-56.stl, pruebaguia4.stl]
2015-08-27 Some bugs fixed
    [pcca2.fcstd, prueba-cover-circle.stl]
2015-08-31 More fixes
    [separador.stl]
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2015-12-03 FreeCAD model updated: Articulation 2 tensioner fixed
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2015-12-15 Separated FreeCAD files uploaded, control script uploaded
    [Thor-Art3.fcstd, Thor-Base.fcstd]
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2015-12-22 Home marks added to FreeCAD files
    [Thor-Base.fcstd]
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2015-12-29 FreeCAD Files & firmware update
    [Configuration.h]
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2016-01-17 KiCad File of Optoisolator PCB added
    [Prueba.kicad_pcb, Prueba.sch]
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2016-01-27 Old files deleted, main file renamed
    [ThorArt1New.fcstd]
2016-02-01 Art 1,2,3 & 4 modified to fix the Opto-isolator PCB
2016-02-03 Some bugs fixed, added Art5 endstop
2016-02-24 Art3 Pulley Fixed
2016-02-24 Bearing Art4 Fixed
2016-02-24 Main FreeCAD File Splitted
    [Art1Body.fcstd, Art1GearMotor.fcstd, Art1OptoFix.fcstd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]
2016-02-25 Art3Body fixed
    [Art3Body.fcstd]
2016-02-29 Art2 BodyAWindow Fixed
    [Art2BodyAWindow.fcstd]
2016-02-29 BaseBot fixed
    [BaseBot.fcstd]
2016-02-29 Art2BodyACover1 fixed
    [Art2BodyACover1.fcstd]
2016-02-29 Art1Body fix
    [Art1Body.fcstd]
2016-03-02 ControlPCB Kicad project added
    [ControlPCB.kicad_pcb, ControlPCB.sch]
2016-03-03 ControlPCB Kicad project update
    [ControlPCB.sch]
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2016-03-04 ControlPCB updated, gerber and drills files added
    [ControlPCB.kicad_pcb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]
2016-03-07 Art4BearingRing fixed
    [Art4BearingRing.fcstd]
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2016-03-14 Art3Pulley Fixed
    [Art3Pulley.fcstd]
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2016-03-15 OptoDisk of Art2&3 added
    [Art23Optodisk.fcstd]
2016-03-16 Assembly minor update. Art1OptoFixFixed. BaseBot Fixed
    [Art1OptoFix.fcstd, BaseBot.fcstd]
2016-03-17 Art1Bot, Art1OptoFix and Assembly Updated
    [Art1OptoFix.fcstd]
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2016-03-21 Some parts fixed, assembly updated!
    [Art1Body.fcstd, Art2BodyACover1.fcstd, Art2MotorGear.fcstd]
2016-03-22 Assembly update, some parts fixed
    [Art3Body.fcstd, Art4MotorGear.fcstd, Art4ody.fcstd]
2016-03-22 Assembly almost done, Art2MotorGear and Art56CoverRing Fixed
    [Art2MotorGear.fcstd, Art56MotorCoverRing.fcstd]
2016-03-29 Added Tensioner freecad files, Assembly updated
    [Art3TensionerBody.fcstd, Art3TensionerPulley.fcstd]
2016-03-29 Assembly fixed
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2016-05-17 Blender files deleted. Them will be moved to a new branch
    [Art1.stl, Art2.stl, Art3.stl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]
2016-05-17 Firmware files deleted. Them will be moved to a new branch
    [Configuration.h, Configuration_adv.h]
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2016-09-29 Some printed parts modified to allow airflow
    [Art1Body.fcstd, Art3Body.fcstd, Art4Body.fcstd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]
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2016-10-25 Art1Top modified - issue#29
    [Art1Top.fcstd]
2016-11-07 Assembly updated, issue solved, ready to merge
    [Art1Body.fcstd, Art1Body.stl, Art1Top.fcstd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]
2016-11-07 Art4OptoFix STL file added
    [Art4OptoFix.stl]
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2016-11-30 mistakes were made
    [ControlPCB.kicad_pcb, _saved_ControlPCB.sch]
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2016-12-19 Added Art2 3D models modified, remixed from Danny-VdH modifications
    [Art2BodyASmall1.stl, Art2BodyASmall2.stl, Art2BodyB.fcstd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]
2016-12-19 KiCAD 3D models paths modified
    [ControlPCB.kicad_pcb]
2016-12-21 Added Art4 3D model modified, remixed from Danny-VdH modifications
    [Art2BodyB.fcstd]
2016-12-21 Added Base 3D model modified, remixed from Ctrl-Alt-Dude modifications
    [BaseBot190mm.fcstd, BaseBot190mm.stl]
2016-12-21 Added Art4 3D model modified, remixed from @Danny-VdH modifications
    [Art4BodySmall1.stl, Art4BodySmall2.stl]
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2017-08-08 STL of full articulations added
    [Art1Thor.stl, Art2Thor.stl, Art3Thor.stl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]
2017-08-08 Art56 splitted in half
    [Art5.stl, Art6.stl]
2017-08-16 Art3 & Base adapted
    [Art3Body.fcstd, BaseBot.fcstd]
2017-08-16 Files redesigned, assembly and step files left
    [Art1OptoFix.stl, Art23Optodisk.fcstd, Art23Optodisk.stl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]
2017-08-17 Commercial Sensors redesign done
    [Art23Optodisk.step, Art23Optodisk.stl, Art2BodyASmall2.step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]
2018-01-10 GripperActiveArmFix & griper STL files generated
    [GripperActiveArm.stl, GripperArm.stl, GripperBot.stl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]
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2018-01-15 filenames fix
    [Art2Union.stl, Art4Optodisk.stl]
2018-01-25 Art56, Gripper and BaseBoxBody modified
    [Art56GearPlate.fcstd, Art56GearPlate.step, Art56GearPlate.stl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]
2018-07-15 BaseBox fixed, Assembly updated
    [BaseBoxBody.FCStd]
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2021-08-02 some deprecated freecad folder removed
    [Art2BodyBCoverSmall.fcstd, Art2BodyBSmall.fcstd, BaseBot190mm.fcstd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]
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2021-08-02 Added FreeCAD files of Thor V2.1 Redesign
    [Art1Body.fcstd, Art1FanHolder.FCStd, Art1GearMotor.fcstd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]
2021-08-02 Added STL files of Thor V2.1 Redesign
    [Art1Body.stl, Art1Bot.stl, Art1FanHolder.stl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]
2021-08-02 Added STEP files of Thor V2.1 Redesign
    [Art1Body.step, Art1FanHolder.step, Art1GearMotor.step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]
2021-09-23 Hotfix Art1Body steppers housing
    [Art1Body.fcstd, Art1Body.step, Art1Body.stl]
2021-09-23 2nd Hotfix Art1Body steppers housing
    [Art1Body.fcstd, Art1Body.step, Art1Body.stl]
2022-05-08 Deleted Art4OptoDisk.stl
    Looks like it's a duplicate of `Art4Optodisk.stl` (lowercase 'd')
    [Art4OptoDisk.stl]
2022-08-02 Added SuctionCupToolHolder FreeCAD, STL and STEP files
    This part is designed to hold a suction cup tool to be used as an end effector.
    [SuctionCupToolHolder.FCStd, SuctionCupToolHolder.step, SuctionCupToolHolder.stl]
2022-08-02 Added SupportRoller part files
    Place a pair of roller bearings into this part with some M5 nuts and bolts and place under Art2 on the side where the joint tends to sag.
    [SupportRoller.FCStd, SupportRoller.step, SupportRoller.stl]
2022-08-02 Added Art4MotorShim part files
    I used this part to move the Art4 motor closer to the Art4TransmissionColumn, closing the gap between the gears and reducing the backlash.
    [Art4MotorShim.fcstd, Art4MotorShim.step, Art4MotorShim.stl]
2022-08-02 Added Art2BodyUnion_mod part files. Increases range of motion Art3.
    Easy to replace, this part will give you approximately 11 extra degrees of range of motion in Art3.
    [Art2BodyUnion_mod.FCStd, Art2BodyUnion_mod.step, Art2BodyUnion_mod.stl]
2022-08-15 Moved mods to a dedicated folder. Cleaned readme file.
    [Art2BodyA_Splitted_A.step, Art2BodyA_Splitted_A.stl, Art2BodyA_Splitted_B.step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]
2023-01-11 Fixed BaseBot.step
    [BaseBot.step]
2023-09-14 Modified Art4BearingRing for tighter fit with 5.98mm ball bearings from AliExpress
    [Art4BearingRing_5.98mm_Balls.step, Art4BearingRing_5.98mm_Balls.stl]
2023-12-07 Added se1exin mod, moved to mods new folder
    [Art4BearingRing_5.98mm_Balls.step, Art4BearingRing_5.98mm_Balls.stl]
2023-12-28 DIY servo connector replaced by GX12
    [Art4Body.fcstd, AssemblyArt4.FCStd]
2023-12-31 GX12 replaced with M8 connector
    [Art4Body.fcstd, AssemblyArt4.FCStd]
2024-01-01 Art4Body and Art56SmallGear modified to ease assembly
    [Art4Body.fcstd]
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2024-02-11 Updated STL & STEP files of Art4Body and Art56SmallGear
    [Art4Body.step, Art4Body.stl, Art56SmallGear.stl]
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
